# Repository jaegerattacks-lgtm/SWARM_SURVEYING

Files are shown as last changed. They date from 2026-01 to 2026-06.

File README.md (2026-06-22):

# SWARM SURVEYING

A modular robotics project for swarm-based surveying, combining robot bring-up, pose handling, mobile app integration, mechanical design, and supporting documentation in one repository.

## Overview

**SWARM SURVEYING** is a project archive for a surveying robot swarm workflow.  
This repository collects the main software packages, mobile app assets, hardware-related files, drawings, and technical appendices used across the project.

The goal of the project is to support a swarm surveying pipeline where robot motion, pose data, and system integration are handled through a coordinated software-and-hardware setup.

## What’s in this repository

- **Appendices** – technical background, design notes, and supporting documentation
- **Robot demo assets** – media showing robot movement and system behavior
- **ARKitRobotApp** – mobile app package for AR/pose-based interaction
- **PoseReceiver** – pose receiving component for system communication
- **Swarm bring-up** – bring-up package for launching or integrating the swarm system
- **Actuator sizing** – sizing and selection material for actuation
- **Parts** – parts list and component references
- **All drawings** – consolidated mechanical or system drawings

## Repository structure

```text
SWARM_SURVEYING/
├── appendices/
├── robot_moving_vid/
├── ARKitRobotApp.zip
├── PoseReceiver.zip
├── actutor_sizing.zip
├── all_drawings.zip
├── parts.zip
└── swarm_bringup-*.zip

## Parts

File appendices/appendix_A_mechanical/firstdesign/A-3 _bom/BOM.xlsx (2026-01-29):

 | Name | QTY | Material | model
1 | Plate | 1 | Acrylic | _
2 | Trailing Arm | 4 | Acrylic | _
3 | support_Arm | 4 | Acrylic | _
4 | spacer_link | 4 | Acrylic | _
5 | Trailing Arm_lcoker | 8 | Acrylic | _
6 | support_Arm_locker | 8 | Acrylic | _
7 | spacer_link_locker | 8 | Acrylic | _
8 | Rear Shaft Axle | 1 | Steel | _
9 | All terrain wheel | 4 | Rubber | _
10 | hex coupling long | 4 | brass | _
11 | Front shaft Axle | 1 | Steel | _
12 | camera holder | 2 | PLA | _
13 | Bearing | 16 | _ | F608ZZ
14 | shaft holder 8mm | 4 | steel | _
15 | suspension | 4 | _ | _
16 | Motor | 4 | _ | SG555123000-30K
17 | Motor Driver | 4 |  | BTS7960
18 | Battery | 9 | _ | _
19 | Esp 32 | 1 | _ | cp2102_30pin
20 | Pcb | 1 | _ | _
21 | BMS | 1 | _ | BMS 4S 18650
22 | Regulator | 1 | _ | _
23 | M3 Bolts 1.5cm | 36 | Steel | _
24 | M3 Bolts 2.5cm | 20 | steel | _
25 | M4 Bolts | 12 | Steel | _
26 | M3 Nuts | 64 | Steel | _
27 | M8 Nuts | 4 | Steel | _
28 | spacer 2cm | 16 | Steel | _
29 | Jumper Wires | 80 | Copper | _
30 | Macrona 1 meter | 7 | Plastic | _
31 | Mobile Iphone 12 | 1 | _ | _

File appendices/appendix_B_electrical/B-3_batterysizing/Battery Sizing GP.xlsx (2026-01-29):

Component | Quantity | Voltage | Current |  |  | Avg Power per unit | Avg Total Power | Max Power per unit | Max Total Power
 |  |  | Idle State | Nominal State | Peak State
Raspberry Pi 5 Model B 16 GB RAM | 1 | 5 | 1 | 2 | 3 | 10 | 10 | 15 | 15
ESP32-S Development Board CH340 | 1 | 3.3 | 0.02 | 0.15 | 0.6 | 0.495 | 0.495 | 1.98 | 1.98
MPU9250 | 1 | 3.3 | 8e-06 | 0.0037 | 0.004 | 0.01221 | 0.01221 | 0.0132 | 0.0132
VL53L1X | 2 | 3.3 | 2e-05 | 0.016 | 0.018 | 0.0528 | 0.1056 | 0.0594 | 0.1188
SG555123000-30K | 4 | 12 | 0.14 | 0.8 | 3 | 9.6 | 38.4 | 36 | 144
BTS7960 | 4 | 5 | - | 0.002 | 0.003 | 0.01 | 0.04 | 0.015 | 0.06
Calculations | Battery Model | INR18650MH1 |  | No. of cells in serires | 3 | - | Max Power | 161.172 | W
 | Desired Work Time | 2 | h | Pack Voltage | 11.1 | V | Avg Power | 49.05281 | W
 | Desired Voltage | 12 | V | No. of cells in parallel | 3 | - | Peak Current | 14.52 | A
 | Cell Voltage | 3.7 | V | Pack Capacity | 9.3 | Ah | Energy | 98.10562 | Wh
 | Cell Capacity | 3.1 | Ah | Pack max Current | 30 | A | Capacity | 8.838344144 | Ah
 | Cell max Current | 10 | A | Total No. of Cells | 9 | - | Min C-Rating | 1.642841664 | C
 |  |  |  | C_Rating | 3.225806452 | C

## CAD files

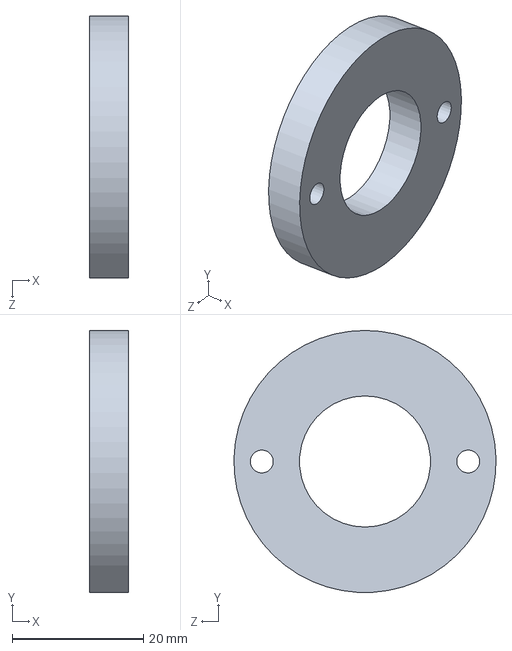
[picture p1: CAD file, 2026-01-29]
appendices/appendix_A_mechanical/firstdesign/A-1_3dcadmodels/Trailing_Arm bearing_locker.SLDPRT
6.00 x 40.0 x 40.0 mm

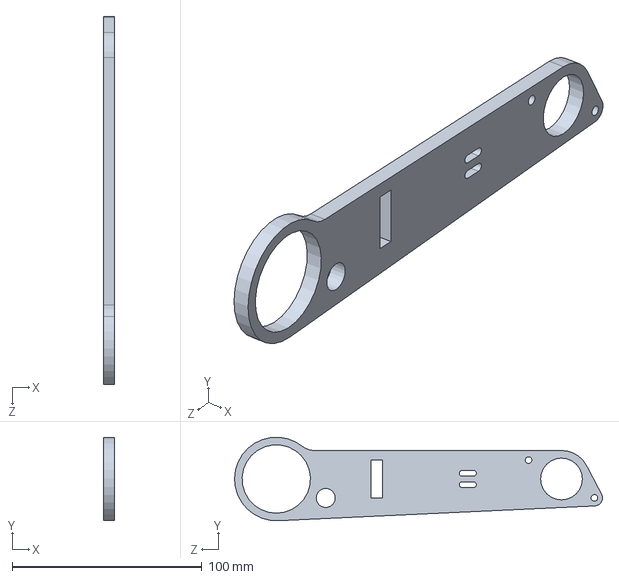
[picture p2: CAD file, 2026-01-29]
appendices/appendix_A_mechanical/firstdesign/A-1_3dcadmodels/Support Link.SLDPRT
6.00 x 43.9 x 193.8 mm

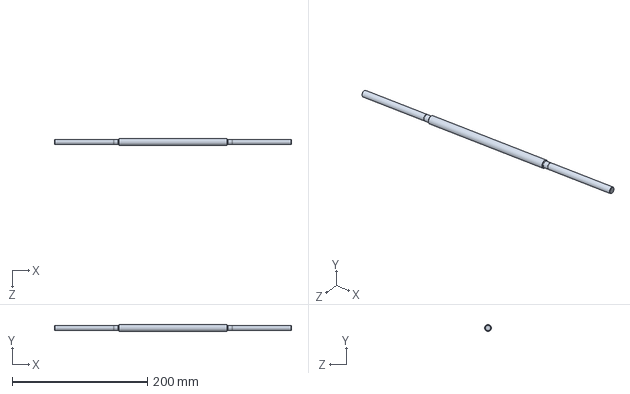
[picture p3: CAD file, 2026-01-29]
appendices/appendix_A_mechanical/firstdesign/A-1_3dcadmodels/Shaft.SLDPRT
350.0 x 10.0 x 10.0 mm

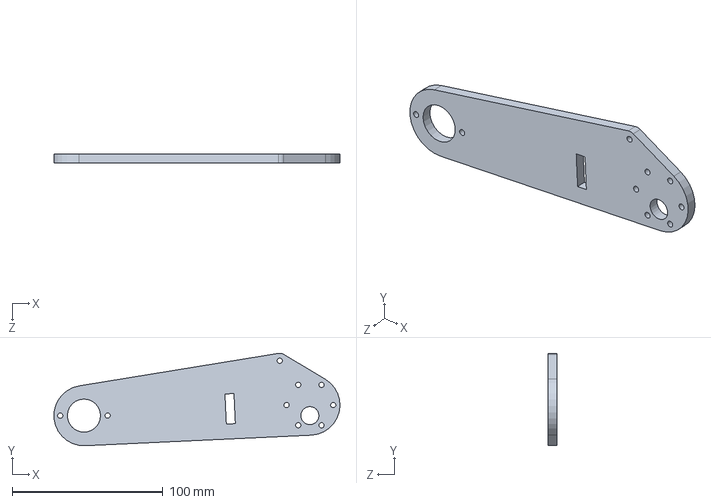
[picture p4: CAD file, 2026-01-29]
appendices/appendix_A_mechanical/firstdesign/A-1_3dcadmodels/Trailing Arm.SLDPRT
189.9 x 61.4 x 6.00 mm

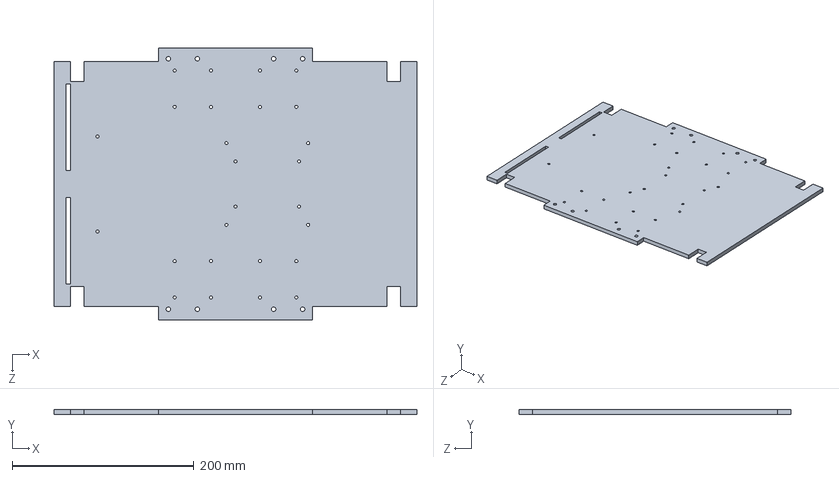
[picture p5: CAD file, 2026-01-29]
appendices/appendix_A_mechanical/firstdesign/A-1_3dcadmodels/Acrylic plate ___.SLDPRT
400.0 x 6.00 x 300.0 mm

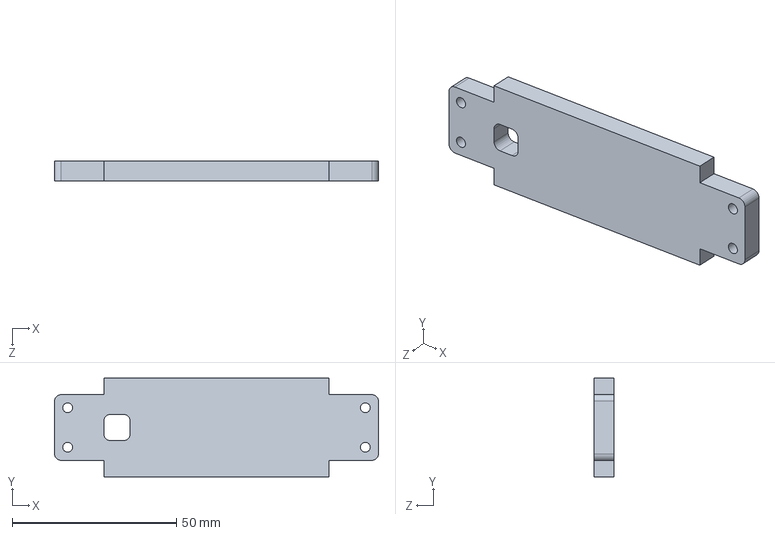
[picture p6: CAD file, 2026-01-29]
appendices/appendix_A_mechanical/firstdesign/A-1_3dcadmodels/Arms link.SLDPRT
98.5 x 30.0 x 6.00 mm

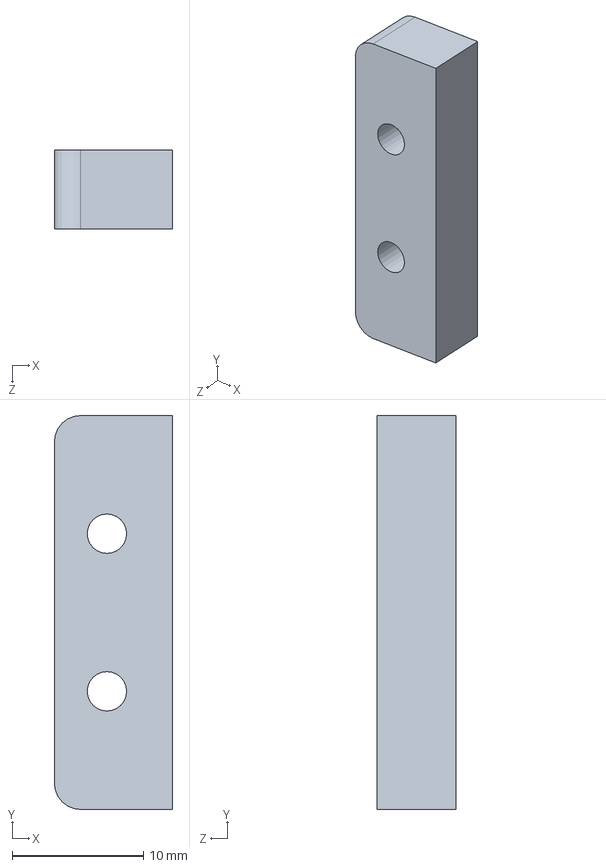
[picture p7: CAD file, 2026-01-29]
appendices/appendix_A_mechanical/firstdesign/A-1_3dcadmodels/spacer_link_locker.SLDPRT
9.00 x 30.0 x 6.00 mm

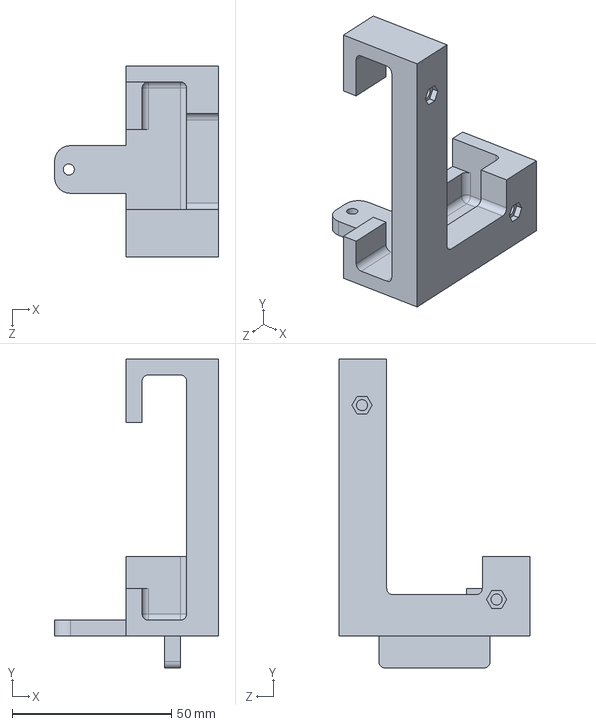
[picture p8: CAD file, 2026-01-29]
appendices/appendix_A_mechanical/firstdesign/A-1_3dcadmodels/fixed part.SLDPRT
51.5 x 97.0 x 60.0 mm

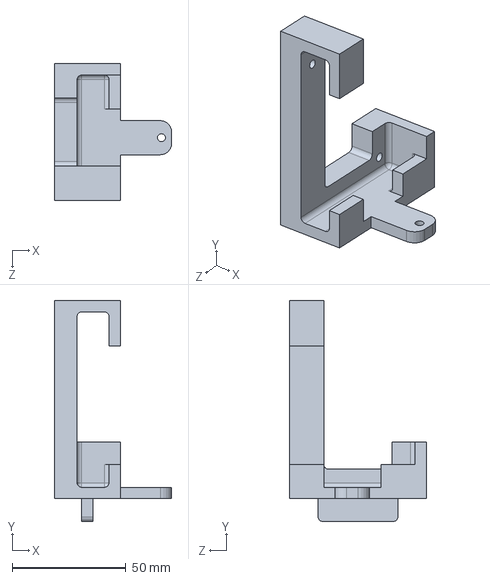
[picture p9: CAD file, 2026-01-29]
appendices/appendix_A_mechanical/firstdesign/A-1_3dcadmodels/fixed_part_mirror.SLDPRT
51.5 x 97.0 x 60.0 mm

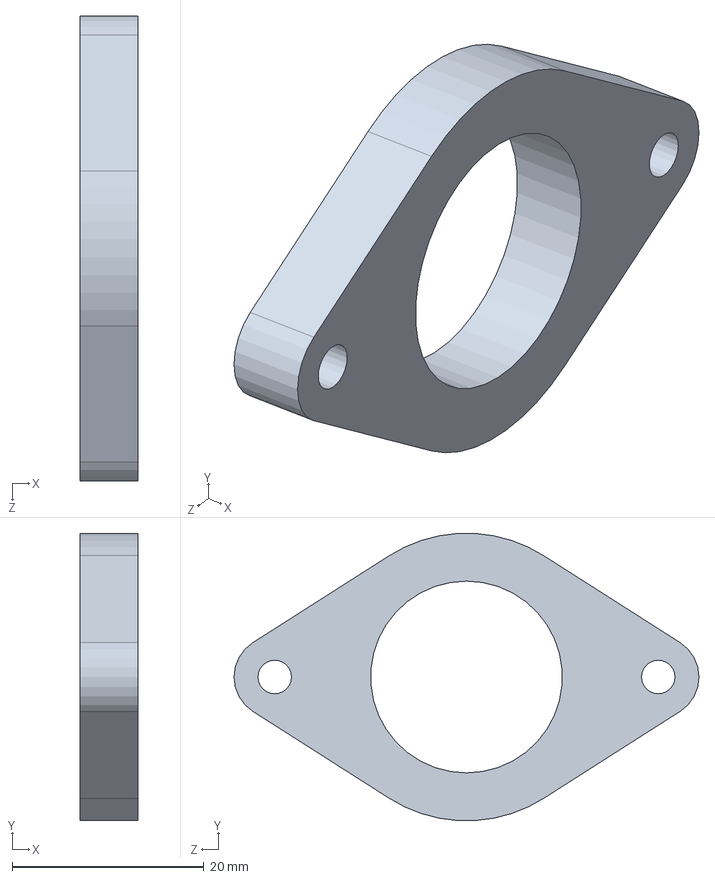
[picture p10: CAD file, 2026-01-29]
appendices/appendix_A_mechanical/firstdesign/A-1_3dcadmodels/support_link_locker.SLDPRT
6.00 x 29.9 x 48.5 mm

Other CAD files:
appendices/appendix_A_mechanical/firstdesign/A-1_3dcadmodels/spacer_link.SLDPRT

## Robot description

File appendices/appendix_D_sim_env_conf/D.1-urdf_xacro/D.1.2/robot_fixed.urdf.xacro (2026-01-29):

<?xml version="1.0"?>
<robot xmlns:xacro="http://www.ros.org/wiki/xacro" name="view_robot_pkg">

  <xacro:arg name="config_file" default=""/>

  <xacro:property name="mesh_path" value="file:///home/nour/my_friend_ws/install/swarm_bringup/share/swarm_bringup/meshes"/>
  
  <link name="base_link"></link>

  <link name="chassis_link">
    <inertial>
      <origin xyz="-0.001 0 0.009" rpy="0 0 0" />
      <mass value="3.0" />
      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
    </inertial>
    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
  </link>

  <joint name="base_to_chassis" type="fixed">
    <parent link="base_link" />
    <child link="chassis_link" />
    <origin xyz="0 0 0" rpy="0 0 0" />
  </joint>

  <xacro:macro name="leg_assembly" params="prefix arm_xyz damper_xyz wheel_xyz piston_xyz piston_rpy wheel_mu arm_inertial_xyz">

    <link name="${prefix}_arm">
      <inertial>
        <origin xyz="${arm_inertial_xyz}" rpy="0 0 0" />
        <mass value="0.147" />
        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
      </inertial>
      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
    </link>

    <joint name="${prefix}_arm_joint" type="revolute">
      <origin xyz="${arm_xyz}" rpy="1.5708 0 0" />
      <parent link="chassis_link" />
      <child link="${prefix}_arm" />
      <axis xyz="0 0 -1" />
      <limit lower="0" upper="0" effort="0" velocity="0" />
    </joint>

    <link name="${prefix}_piston">
      <inertial>
        <origin xyz="0 0 0" rpy="0 0 0" />
        <mass value="0.001" />
        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
      </inertial>
      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
      </link>

    <joint name="${prefix}_piston_joint" type="revolute">
      <origin xyz="${piston_xyz}" rpy="${piston_rpy}" />
      <parent link="${prefix}_arm" />
      <child link="${prefix}_piston" />
      <axis xyz="0 0 -1" />
      <limit lower="0" upper="0" effort="0" velocity="0" />
    </joint>

    <link name="${prefix}_damper">
      <inertial>
        <origin xyz="0 0 0" rpy="0 0 0" />
        <mass value="0.018" />
        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
      </inertial>
      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
      </link>

    <joint name="${prefix}_damper_joint" type="revolute">
      <origin xyz="${damper_xyz}" rpy="1.5708 0 0" />
      <parent link="chassis_link" />
      <child link="${prefix}_damper" />
      <axis xyz="0 0 -1" />
      <limit lower="0" upper="0" effort="0" velocity="0" />
    </joint>

    <link name="${prefix}_wheel">
      <inertial>
        <origin xyz="0 0 0" rpy="0 0 0" />
        <mass value="0.096" />
        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
      </inertial>
      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
    </link>

    <joint name="${prefix}_wheel_joint" type="continuous">
      <origin xyz="${wheel_xyz}" rpy="0 0 0" />
      <parent link="${prefix}_arm" />
      <child link="${prefix}_wheel" />
      <axis xyz="0 0 -1" />
    </joint>

    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

  </xacro:macro>

  <xacro:leg_assembly prefix="front_right" arm_xyz="0.059 -0.154 -0.026" damper_xyz="0.175 -0.147 0.081" wheel_xyz="0.136 -0.061 0.058" piston_xyz="0.133 0.020 -0.007" piston_rpy="0 0 0" wheel_mu="1.2" arm_inertial_xyz="0.117 -0.045 -0.033" />

  <xacro:leg_assembly prefix="front_left" arm_xyz="0.059 0.154 -0.026" damper_xyz="0.175 0.147 0.081" wheel_xyz="0.136 -0.061 -0.058" piston_xyz="0.133 -0.02 0.007" piston_rpy="0 0 0" wheel_mu="1.2" arm_inertial_xyz="0.119 -0.039 0.033" />

  <xacro:leg_assembly prefix="back_right" arm_xyz="-0.056 -0.154 -0.026" damper_xyz="-0.172 -0.147 0.081" wheel_xyz="-0.136 -0.061 0.058" piston_xyz="-0.133 -0.020 -0.007" piston_rpy="0 0 0" wheel_mu="0.01" arm_inertial_xyz="-0.117 -0.045 -0.033" />

  <xacro:leg_assembly prefix="back_left" arm_xyz="-0.056 0.154 -0.026" damper_xyz="-0.172 0.147 0.081" wheel_xyz="-0.136 -0.061 -0.058" piston_xyz="-0.133 -0.020 0.007" piston_rpy="0 0 0" wheel_mu="0.01" arm_inertial_xyz="-0.117 -0.044 0.033" />

  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

  <link name="camera_link">
    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
    <inertial>
      <mass value="0.05"/>
      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
    </inertial>
  </link>

  <joint name="camera_joint" type="fixed">
    <parent link="chassis_link"/>
    <child link="camera_link"/>
    <origin xyz="0.18 0.05 0.06" rpy="0 0 0"/>
  </joint>

  <link name="camera_link_optical"></link>
  <joint name="camera_optical_joint" type="fixed">
    <parent link="camera_link"/>
    <child link="camera_link_optical"/>
    <origin xyz="0 0 0" rpy="-1.5708 0 -1.5708"/>
  </joint>

  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

  <ros2_control name="GazeboSystem" type="system">
    <hardware>
      <plugin>gazebo_ros2_control/GazeboSystem</plugin>
    </hardware>

    <xacro:macro name="wheel_interface" params="prefix">
      <joint name="${prefix}_wheel_joint">
        <command_interface name="velocity">
          <param name="min">-10</param>
          <param name="max">10</param>
        </command_interface>
        <state_interface name="velocity"/>
        <state_interface name="position"/>
      </joint>
    </xacro:macro>
    <xacro:wheel_interface prefix="front_left"/>
    <xacro:wheel_interface prefix="front_right"/>
    <xacro:wheel_interface prefix="back_left"/>
    <xacro:wheel_interface prefix="back_right"/>

    <xacro:macro name="passive_interface" params="prefix suffix">
      <joint name="${prefix}_${suffix}_joint">
        <state_interface name="position"/>
      </joint>
    </xacro:macro>
    <xacro:passive_interface prefix="front_left" suffix="arm"/>
    <xacro:passive_interface prefix="front_right" suffix="arm"/>
    <xacro:passive_interface prefix="back_left" suffix="arm"/>
    <xacro:passive_interface prefix="back_right" suffix="arm"/>
    <xacro:passive_interface prefix="front_left" suffix="piston"/>
    <xacro:passive_interface prefix="front_right" suffix="piston"/>
    <xacro:passive_interface prefix="back_left" suffix="piston"/>
    <xacro:passive_interface prefix="back_right" suffix="piston"/>
    <xacro:passive_interface prefix="front_left" suffix="damper"/>
    <xacro:passive_interface prefix="front_right" suffix="damper"/>
    <xacro:passive_interface prefix="back_left" suffix="damper"/>
    <xacro:passive_interface prefix="back_right" suffix="damper"/>
  </ros2_control>

  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

</robot>

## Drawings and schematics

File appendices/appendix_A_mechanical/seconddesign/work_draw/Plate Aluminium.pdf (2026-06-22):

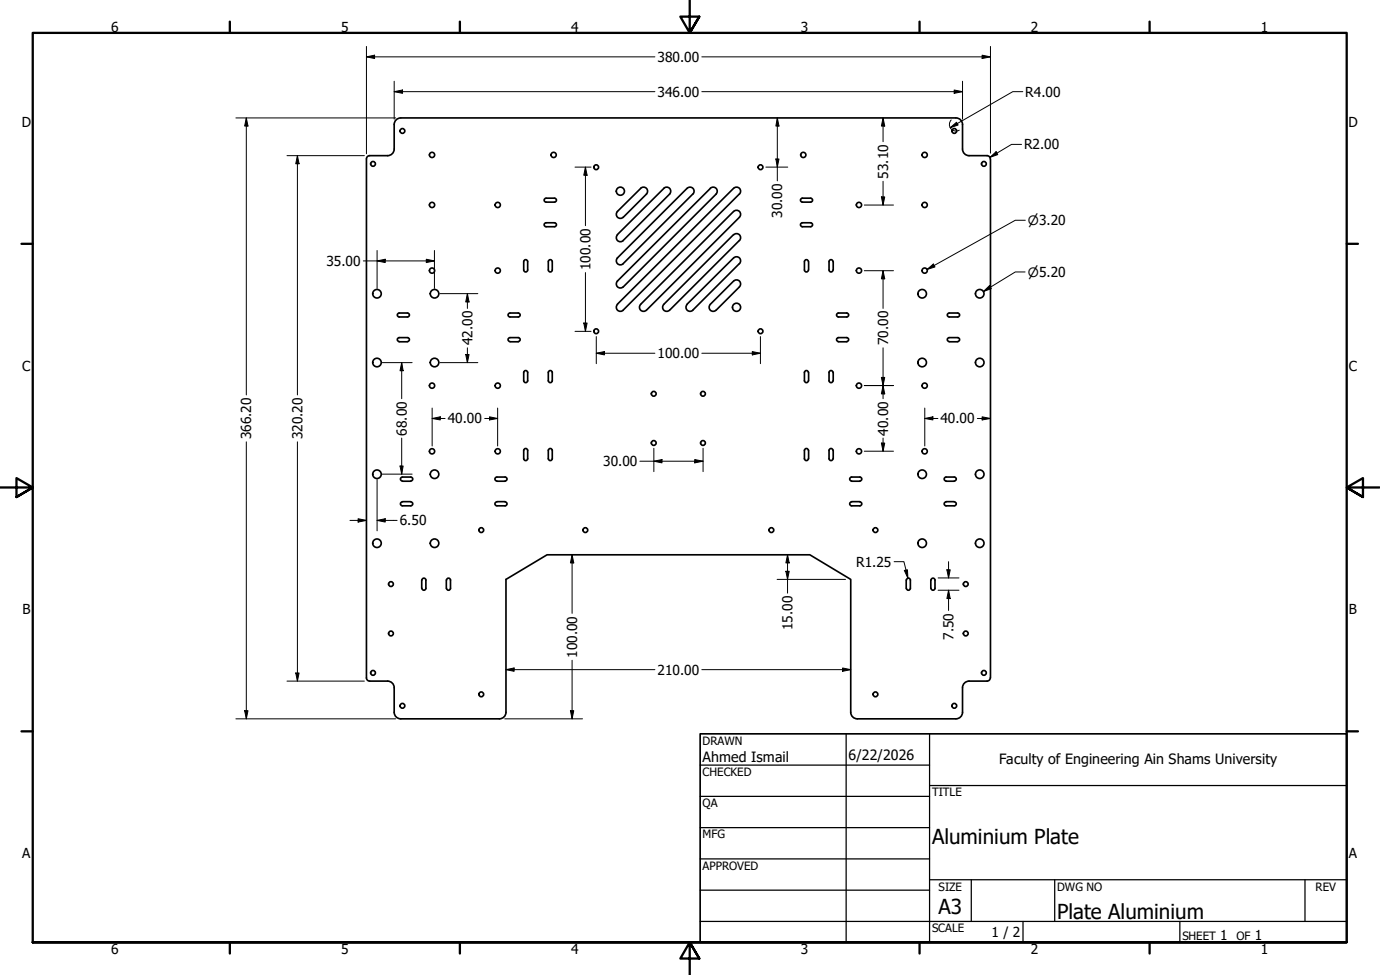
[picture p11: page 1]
Aluminium Plate

DRAWN Ahmed Ismail | 6/22/2026 | Faculty of Engineering Ain Shams University

CHECKED

MFG

APPROVED

SIZE A3 | DWG NO Plate Aluminium | REV

SCALE 1 / 2 | | SHEET 1 OF 1

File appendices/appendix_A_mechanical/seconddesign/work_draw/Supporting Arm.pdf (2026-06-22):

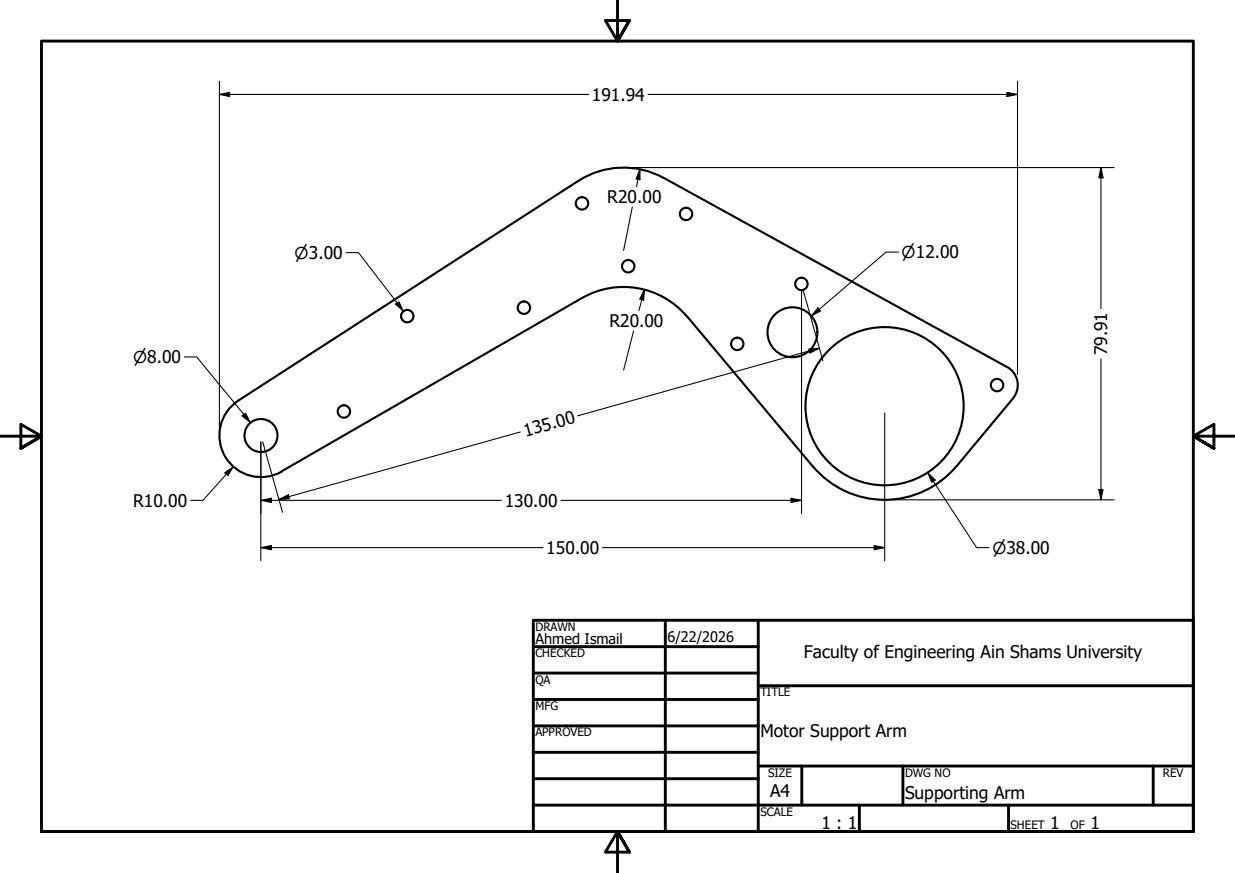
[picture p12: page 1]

DRAWN Ahmed Ismail | 6/22/2026 | Faculty of Engineering Ain Shams University

CHECKED

MFG

APPROVED

Motor Support Arm

SIZE A4 | DWG NO Supporting Arm | REV

SCALE 1 : 1 | | SHEET 1 OF 1

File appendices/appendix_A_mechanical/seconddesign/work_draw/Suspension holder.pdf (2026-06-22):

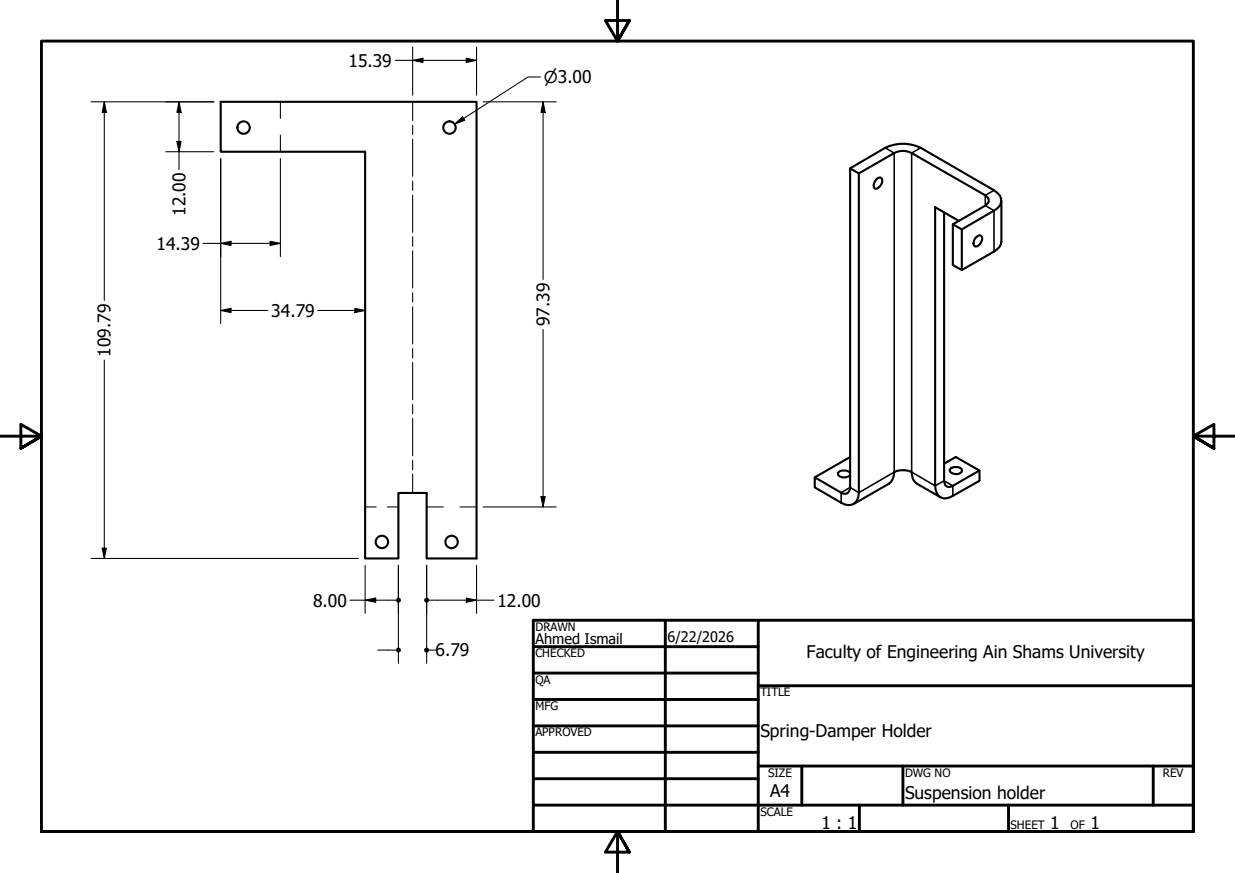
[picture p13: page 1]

DRAWN Ahmed Ismail | 6/22/2026 | Faculty of Engineering Ain Shams University

CHECKED

MFG

APPROVED

Spring-Damper Holder

SIZE A4 | DWG NO Suspension holder | REV

SCALE 1 : 1 | | SHEET 1 OF 1

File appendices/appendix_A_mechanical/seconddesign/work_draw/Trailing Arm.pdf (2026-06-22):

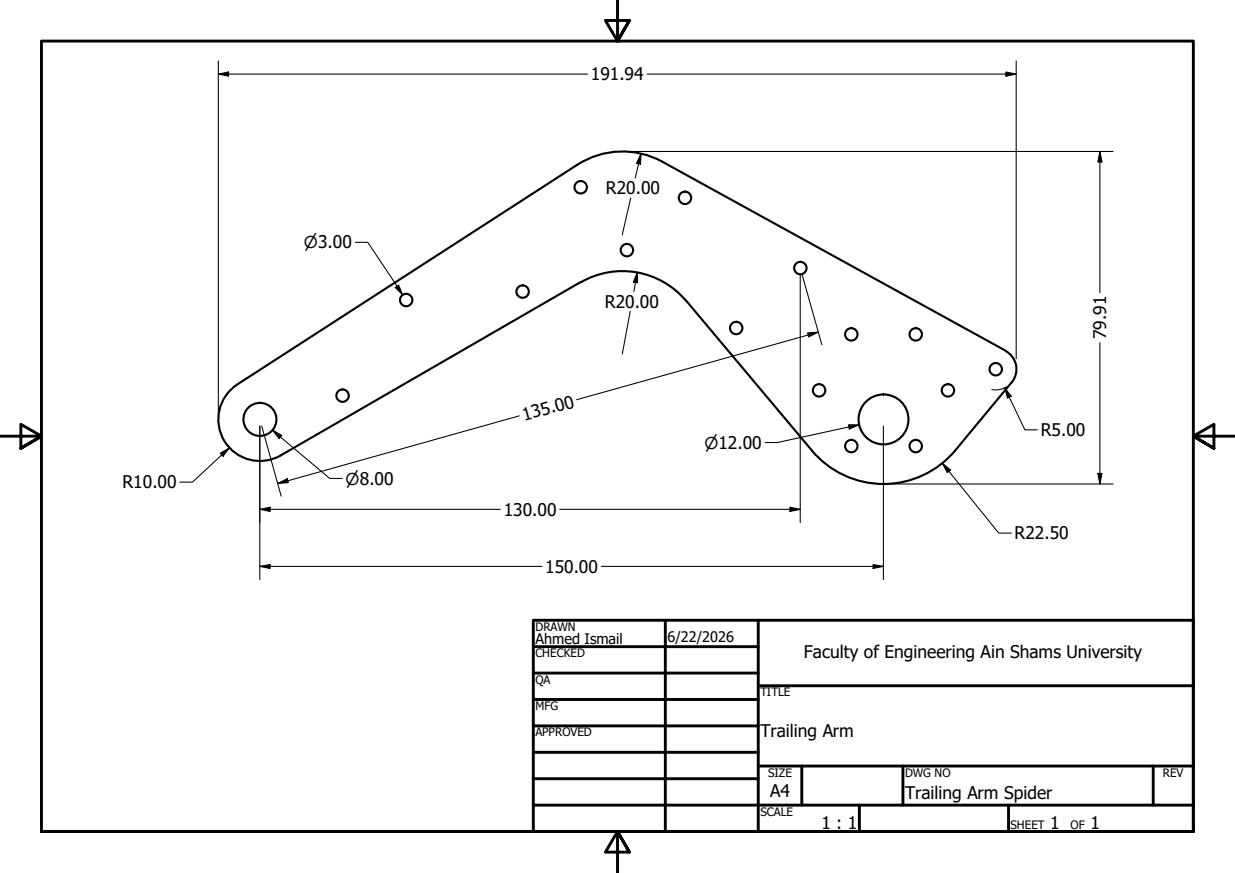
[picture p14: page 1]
Trailing Arm

DRAWN Ahmed Ismail | 6/22/2026 | Faculty of Engineering Ain Shams University

CHECKED

MFG

APPROVED

SIZE A4 | DWG NO Trailing Arm Spider | REV

SCALE 1 : 1 | | SHEET 1 OF 1

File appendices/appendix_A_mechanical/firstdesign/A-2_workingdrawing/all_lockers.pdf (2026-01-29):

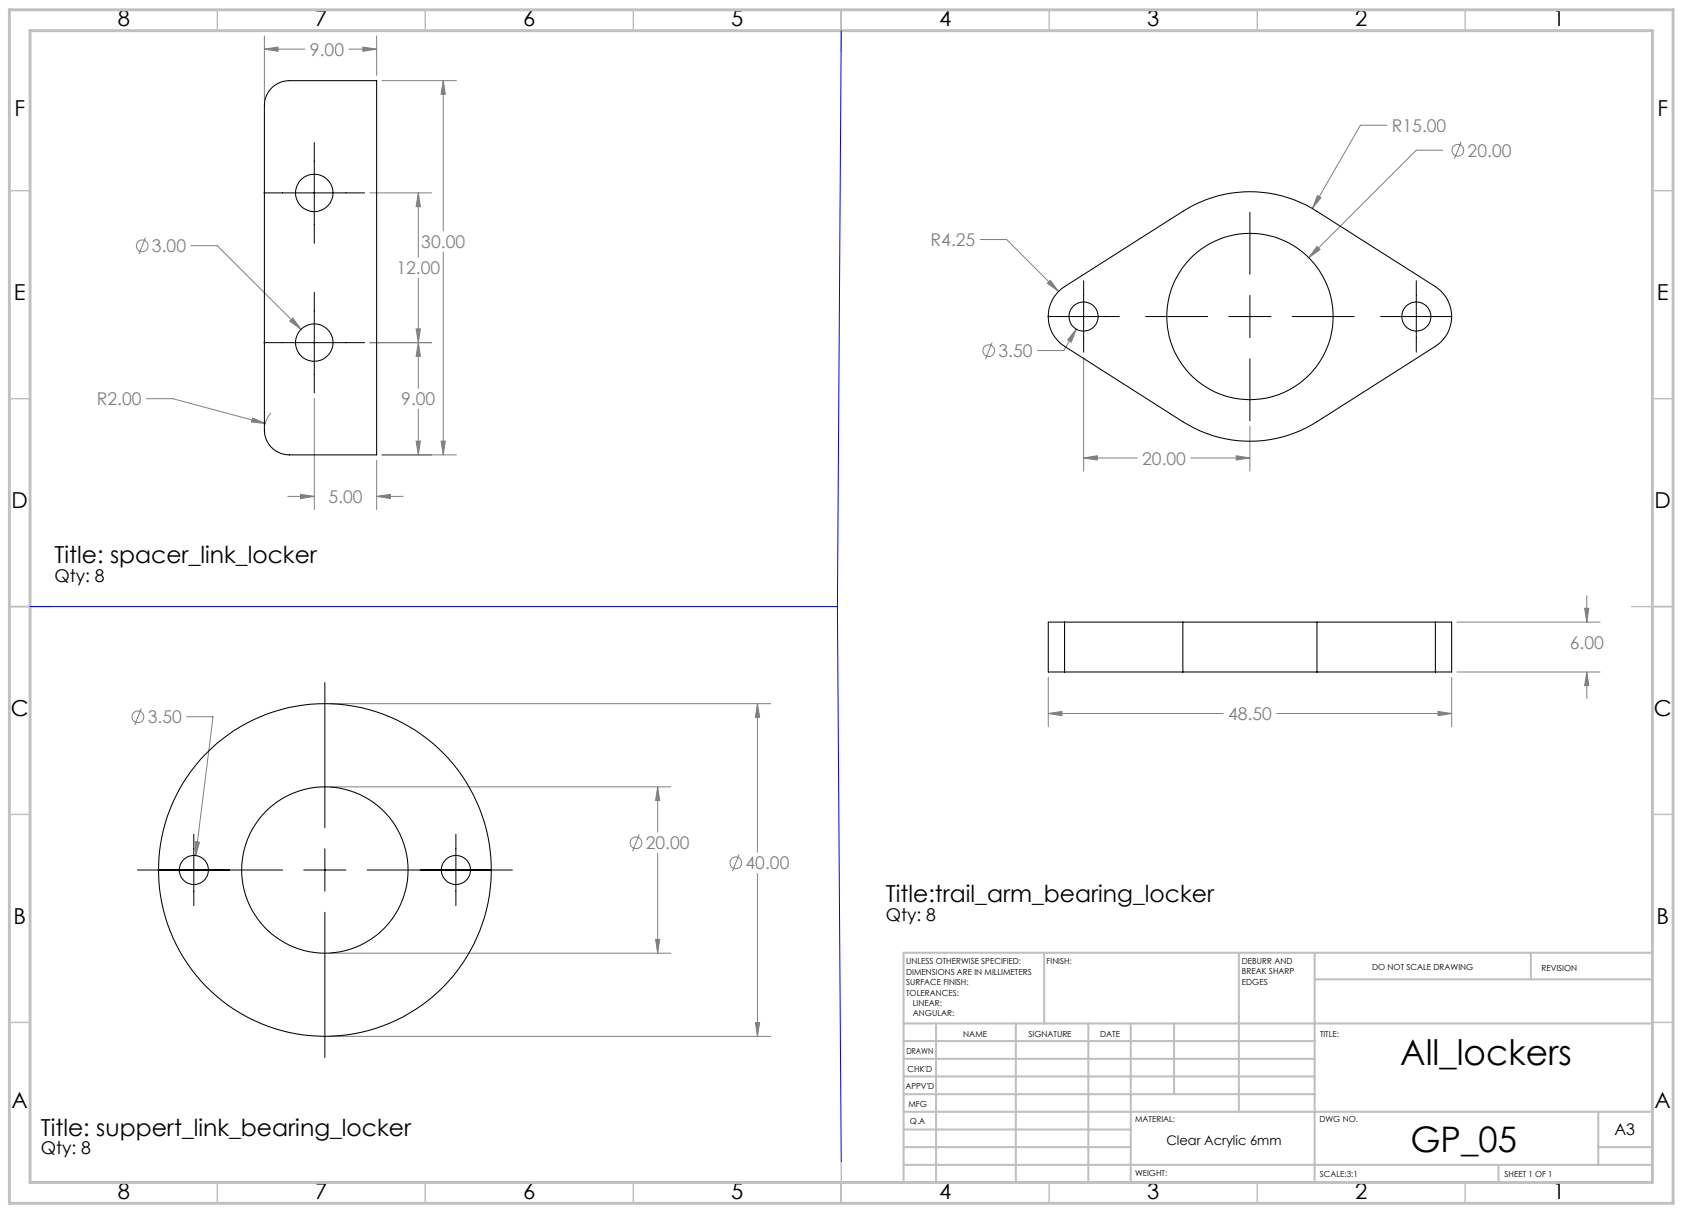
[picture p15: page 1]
Title: spacer_link_locker Qty: 8; Qty: 8; Title: suppert_link_bearing_locker Qty: 8; FINISH:; DEBURR AND; BREAK SHARP; DO NOT SCALE DRAWING; REVISION; SCALE:3:1; SHEET 1 OF 1

UNLESS OTHERWISE SPECIFIED:
DIMENSIONS ARE IN MILLIMETERS
SURFACE FINISH:
TOLERANCES:
LINEAR:
ANGULAR:

NAME | SIGNATURE | DATE | | | | TITLE: All_lockers

DRAWN
CHK'D
APPV'D
MFG
Q.A | | | | MATERIAL: | DWG NO. GP_05 | A3 Clear Acrylic 6mm

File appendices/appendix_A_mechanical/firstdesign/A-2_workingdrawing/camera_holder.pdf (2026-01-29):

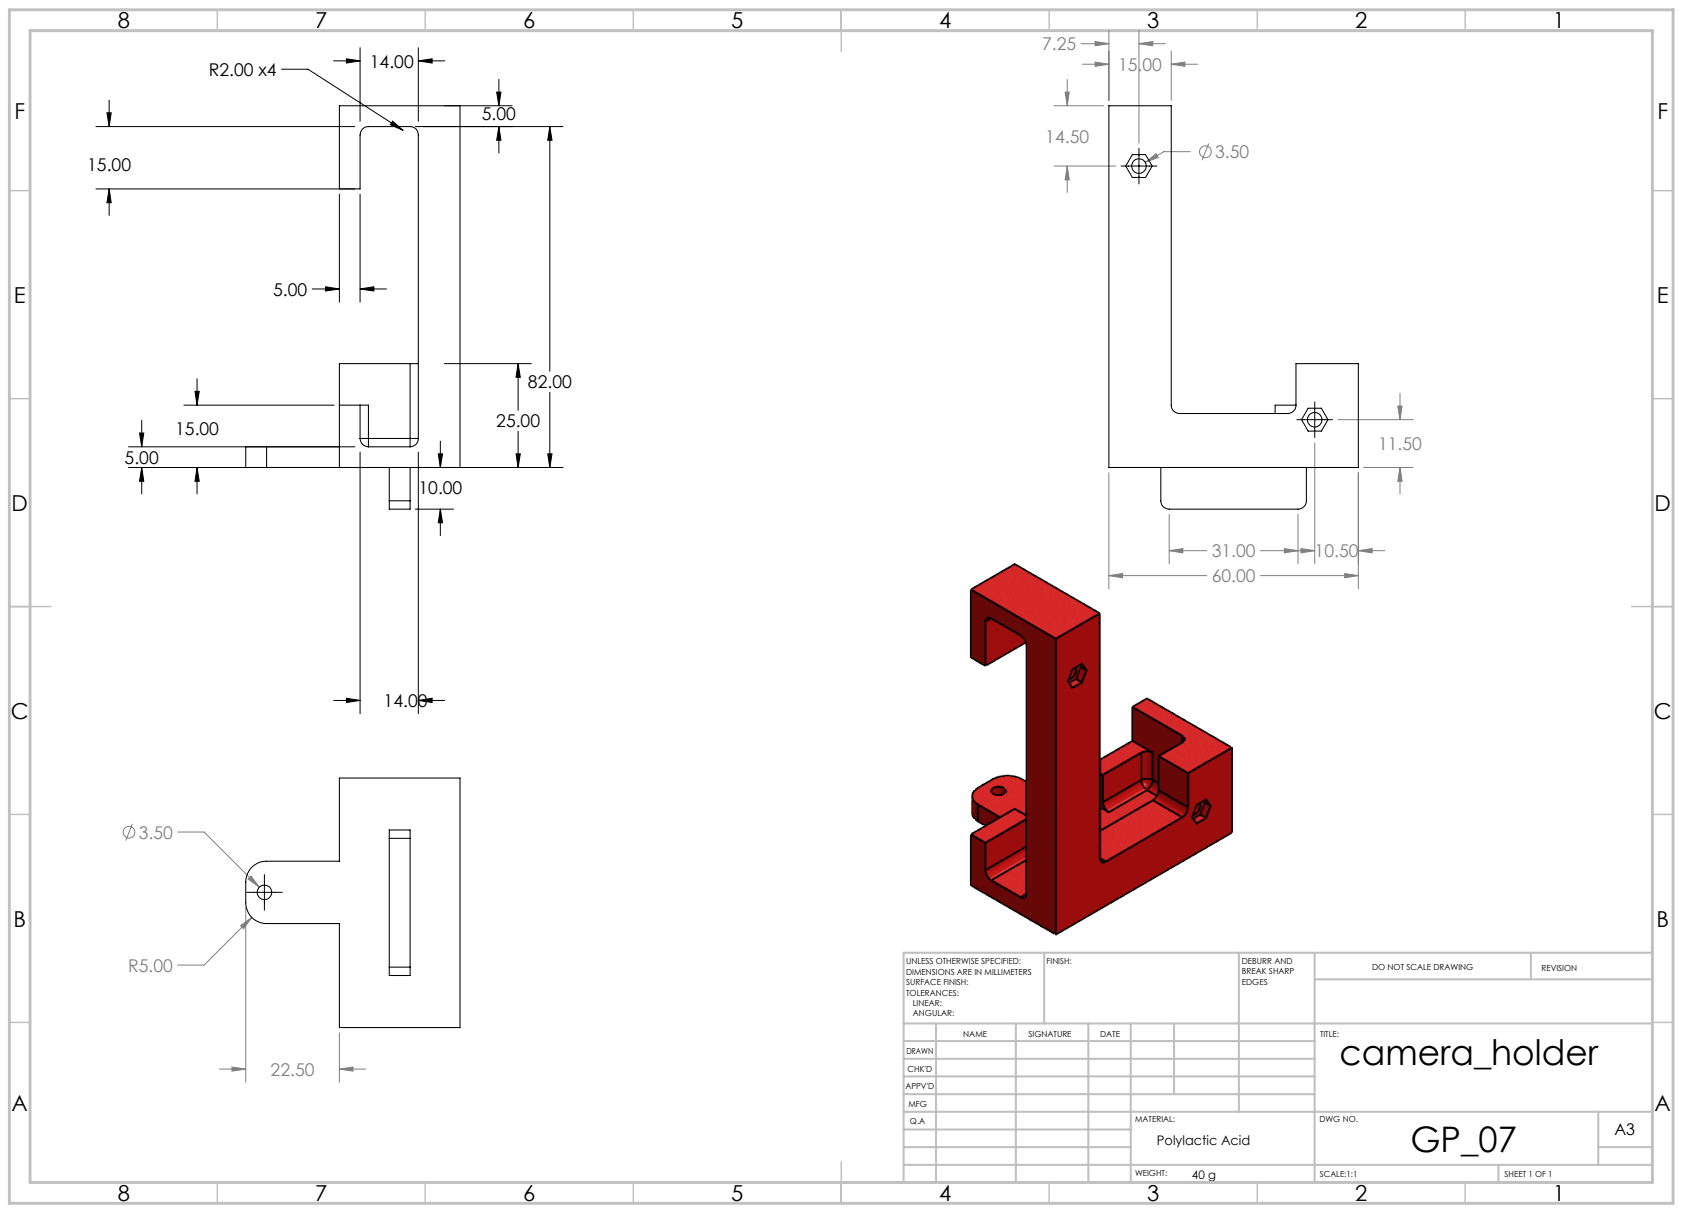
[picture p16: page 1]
FINISH:; DEBURR AND; BREAK SHARP; DO NOT SCALE DRAWING; REVISION; SCALE:1:1; SHEET 1 OF 1

UNLESS OTHERWISE SPECIFIED:
DIMENSIONS ARE IN MILLIMETERS
SURFACE FINISH:
TOLERANCES:
LINEAR:
ANGULAR:

NAME | SIGNATURE | DATE | | | | TITLE: camera_holder

DRAWN
CHK'D
APPV'D
MFG
Q.A | | | | MATERIAL: | DWG NO. GP_07 | A3 Polylactic Acid

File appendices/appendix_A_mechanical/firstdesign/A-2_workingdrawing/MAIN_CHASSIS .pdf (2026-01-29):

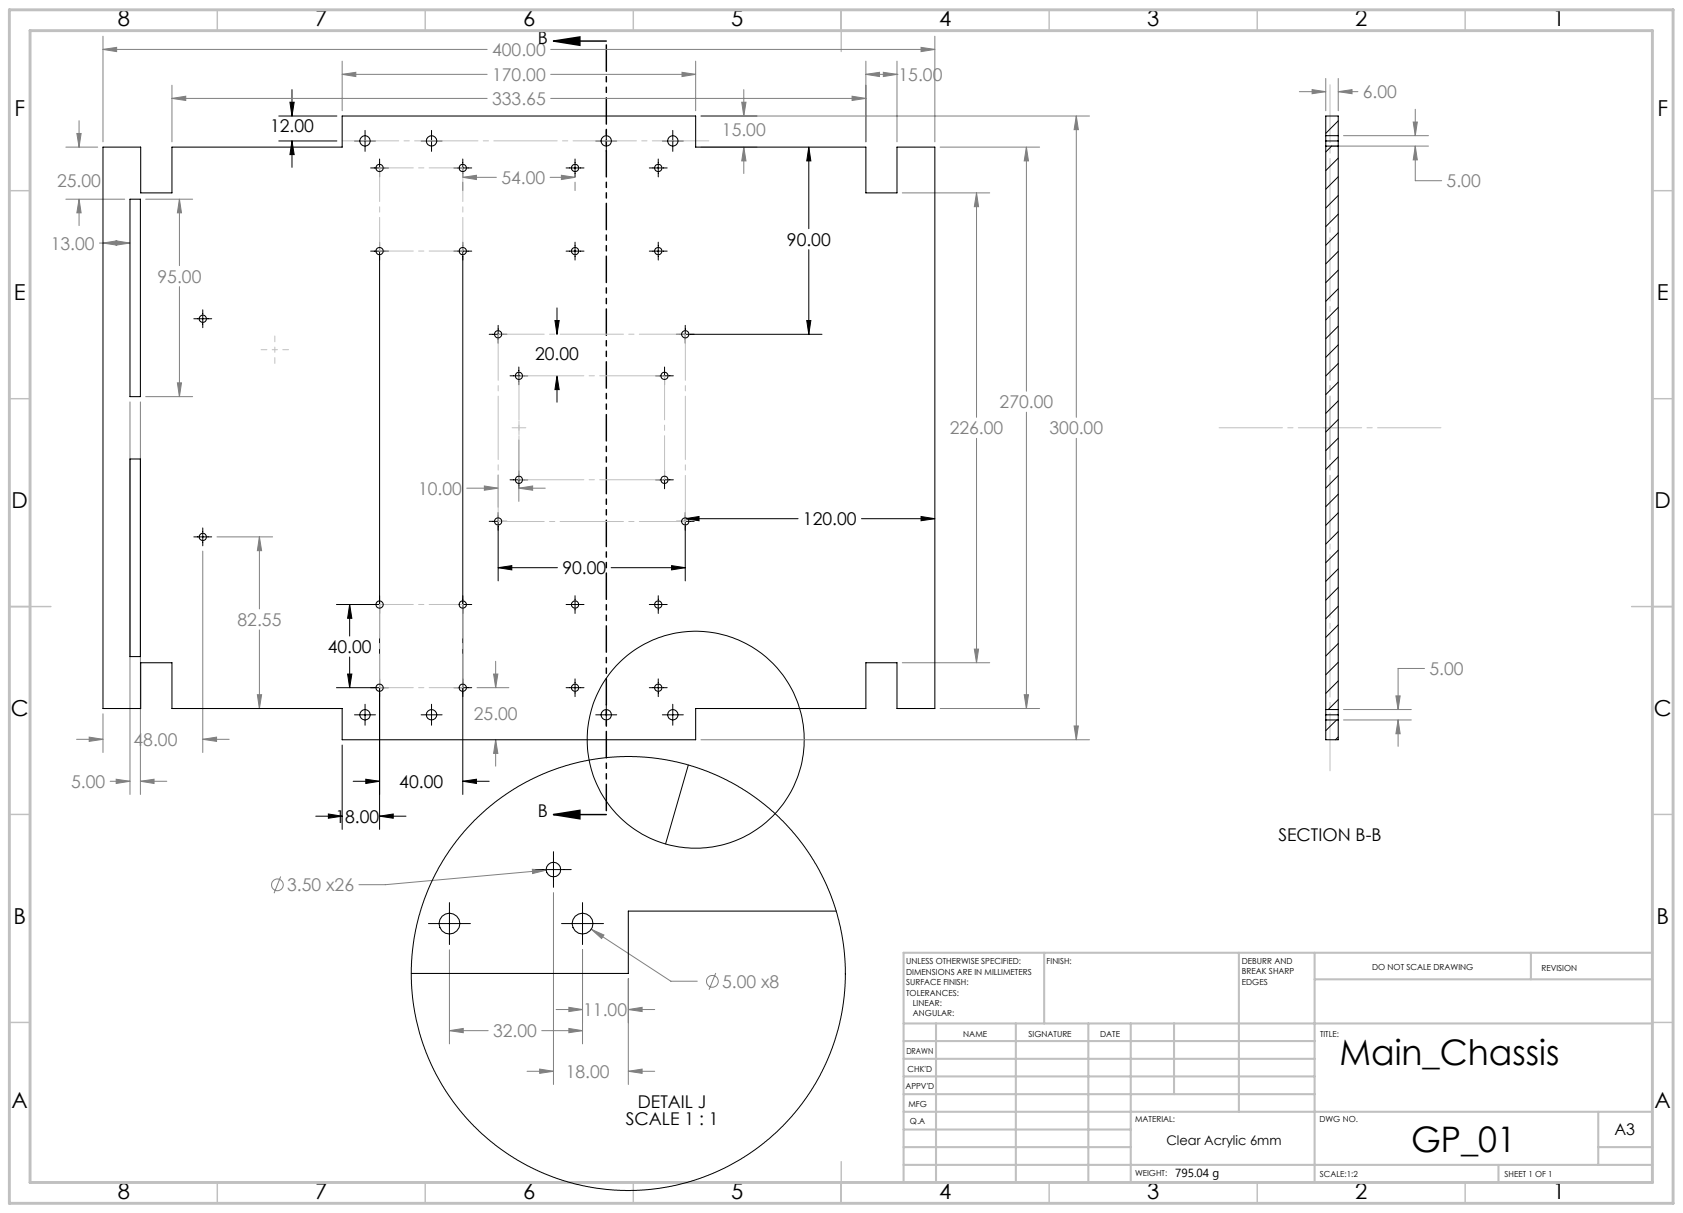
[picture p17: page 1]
SECTION B-B; DETAIL J SCALE 1 : 1; FINISH:; DEBURR AND; BREAK SHARP; DO NOT SCALE DRAWING; REVISION; SCALE:1:2; SHEET 1 OF 1

UNLESS OTHERWISE SPECIFIED:
DIMENSIONS ARE IN MILLIMETERS
SURFACE FINISH:
TOLERANCES:
LINEAR:
ANGULAR:

NAME | SIGNATURE | DATE | | | | TITLE: Main_Chassis

DRAWN
CHK'D
APPV'D
MFG
Q.A | | | | MATERIAL: | DWG NO. GP_01 | A3 Clear Acrylic 6mm

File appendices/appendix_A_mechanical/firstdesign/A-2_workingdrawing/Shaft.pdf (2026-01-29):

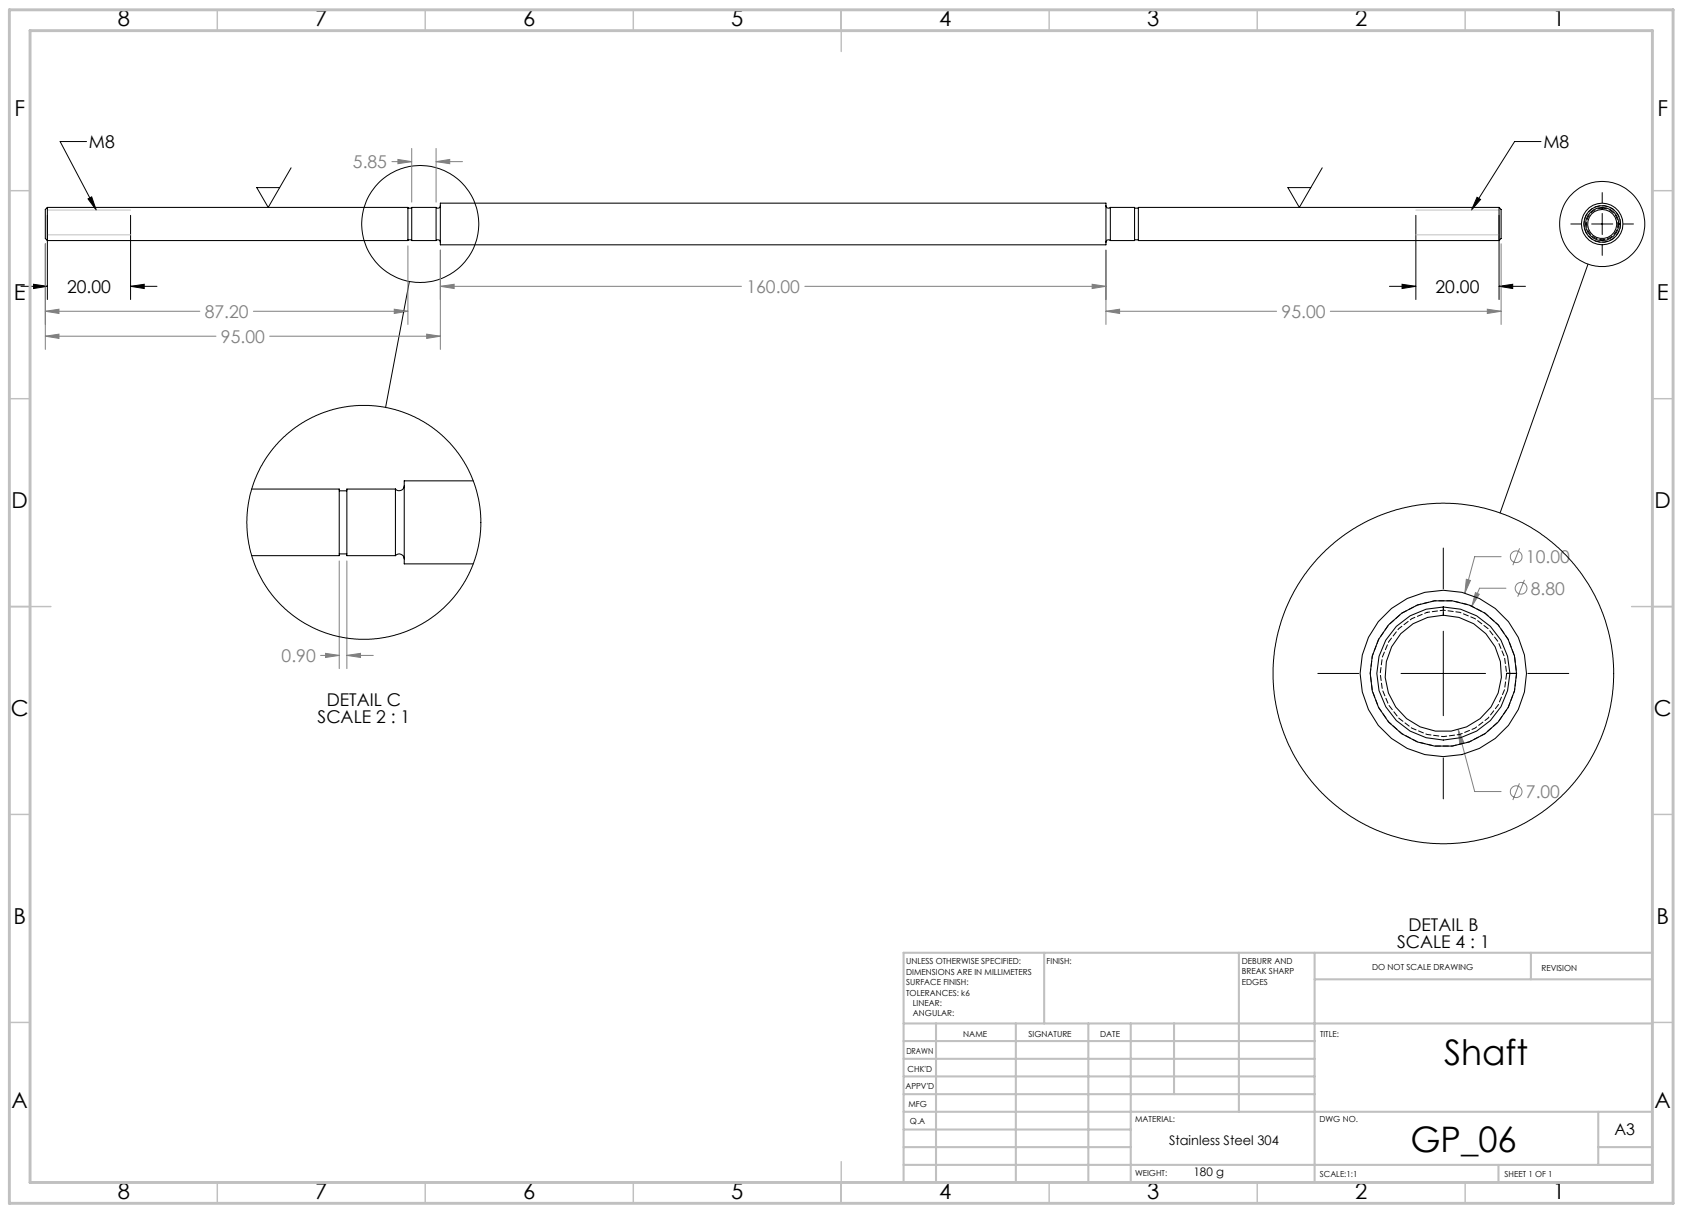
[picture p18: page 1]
DETAIL B SCALE 4 : 1; DETAIL C SCALE 2 : 1; FINISH:; DEBURR AND; BREAK SHARP; DO NOT SCALE DRAWING; REVISION; SCALE:1:1; SHEET 1 OF 1

UNLESS OTHERWISE SPECIFIED:
DIMENSIONS ARE IN MILLIMETERS
SURFACE FINISH:
TOLERANCES: k6
LINEAR:
ANGULAR:

NAME | SIGNATURE | DATE | | | | TITLE: Shaft

DRAWN
CHK'D
APPV'D
MFG
Q.A | | | | MATERIAL: | DWG NO. GP_06 | A3 Stainless Steel 304

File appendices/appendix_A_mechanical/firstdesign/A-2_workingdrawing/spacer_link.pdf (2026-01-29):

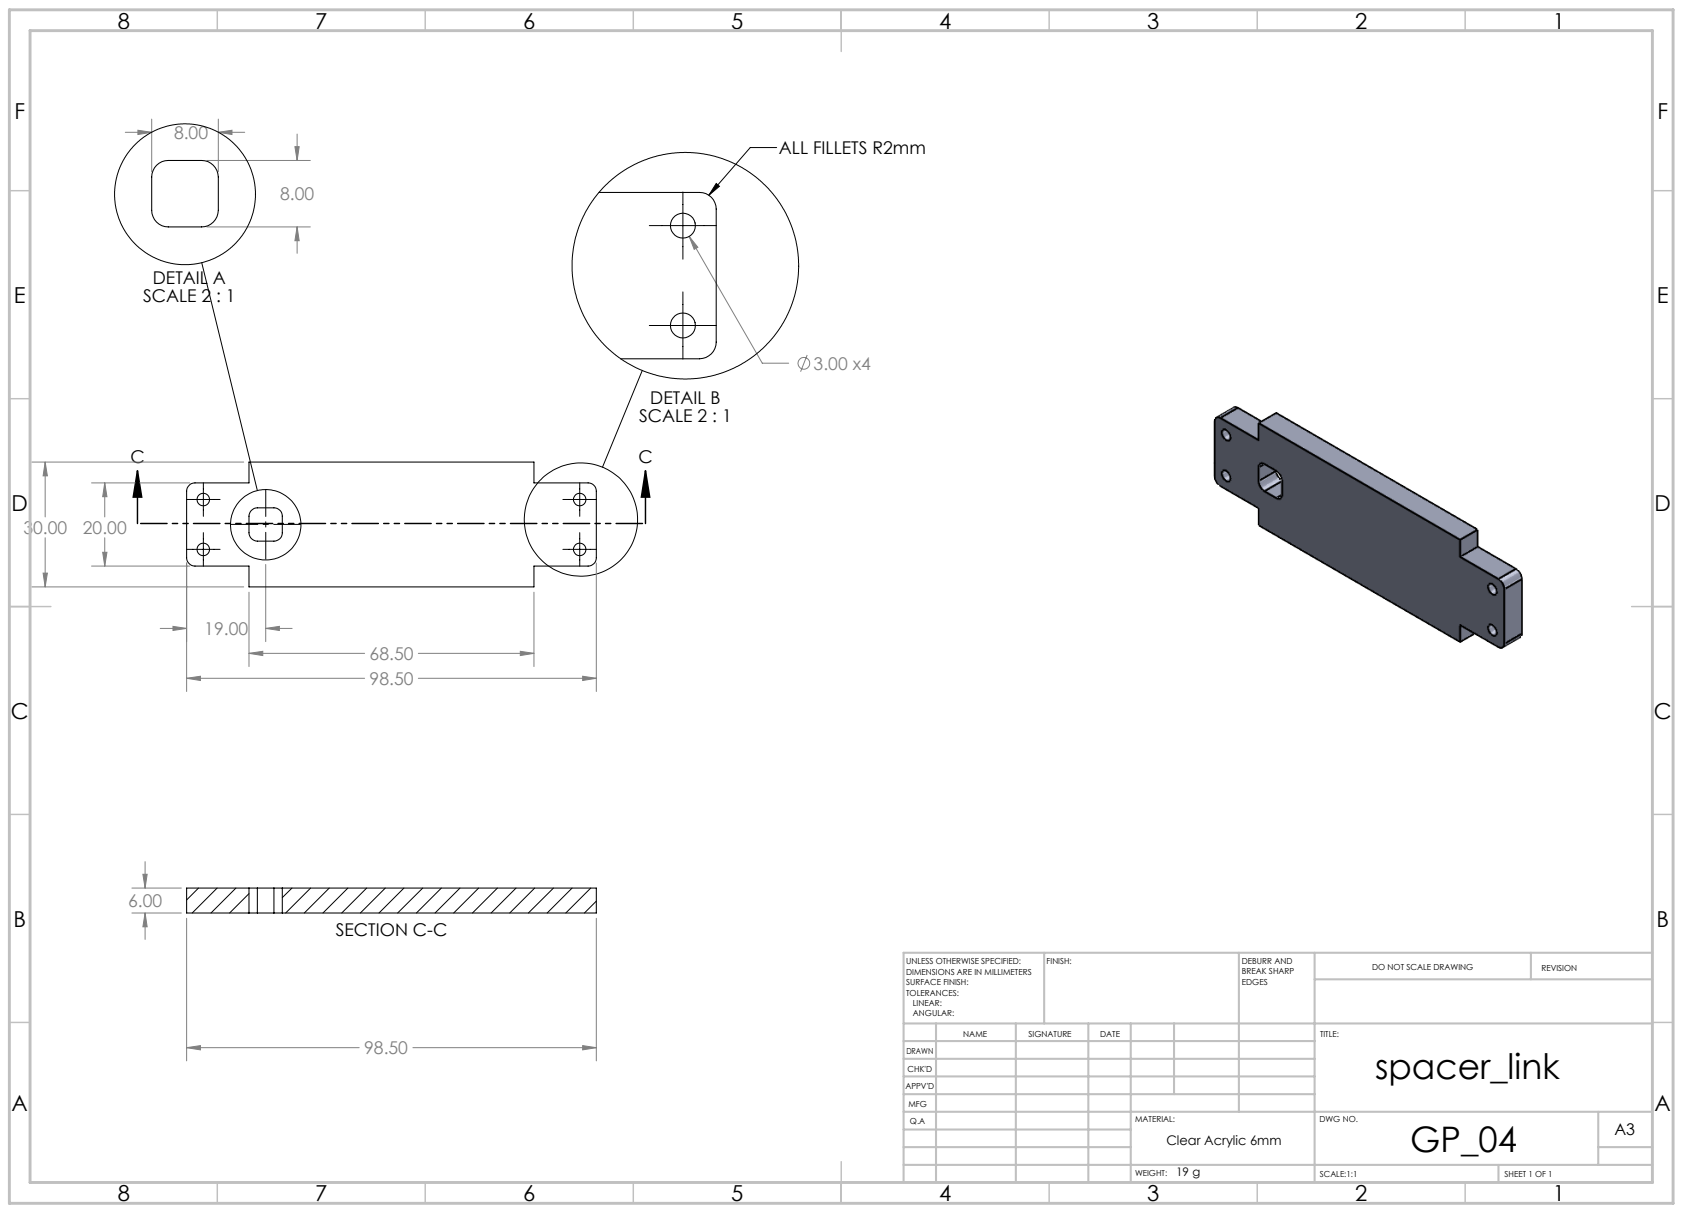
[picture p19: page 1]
DETAIL A SCALE 2 : 1; DETAIL B SCALE 2 : 1; ALL FILLETS R2mm; SECTION C-C; FINISH:; DEBURR AND; BREAK SHARP; DO NOT SCALE DRAWING; REVISION; SCALE:1:1; SHEET 1 OF 1

UNLESS OTHERWISE SPECIFIED:
DIMENSIONS ARE IN MILLIMETERS
SURFACE FINISH:
TOLERANCES:
LINEAR:
ANGULAR:

NAME | SIGNATURE | DATE | | | | TITLE: spacer_link

DRAWN
CHK'D
APPV'D
MFG
Q.A | | | | MATERIAL: | DWG NO. GP_04 | A3 Clear Acrylic 6mm

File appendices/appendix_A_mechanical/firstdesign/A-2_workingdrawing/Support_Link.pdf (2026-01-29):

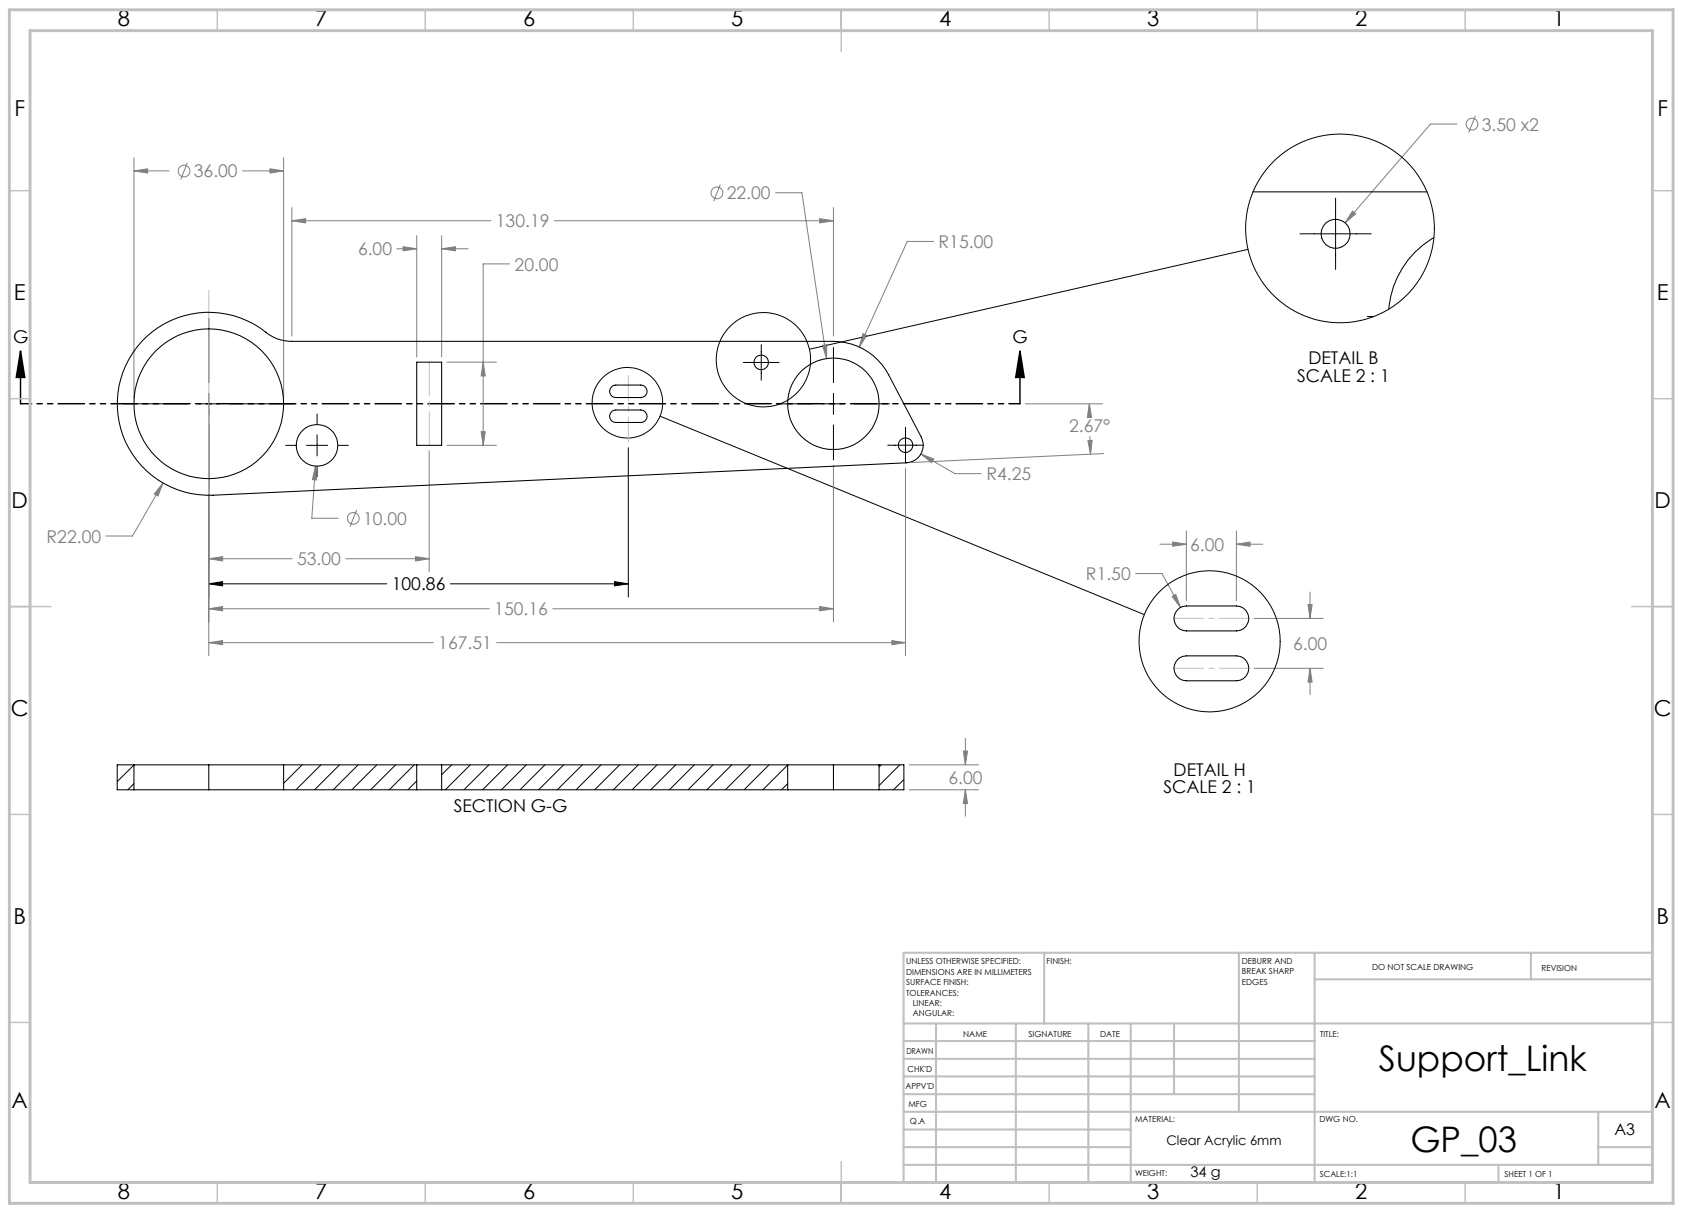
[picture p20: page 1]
DETAIL B SCALE 2 : 1; SECTION G-G; DETAIL H SCALE 2 : 1; FINISH:; DEBURR AND; BREAK SHARP; DO NOT SCALE DRAWING; REVISION; SCALE:1:1; SHEET 1 OF 1

UNLESS OTHERWISE SPECIFIED:
DIMENSIONS ARE IN MILLIMETERS
SURFACE FINISH:
TOLERANCES:
LINEAR:
ANGULAR:

NAME | SIGNATURE | DATE | | | | TITLE: Support_Link

DRAWN
CHK'D
APPV'D
MFG
Q.A | | | | MATERIAL: | DWG NO. GP_03 | A3 Clear Acrylic 6mm

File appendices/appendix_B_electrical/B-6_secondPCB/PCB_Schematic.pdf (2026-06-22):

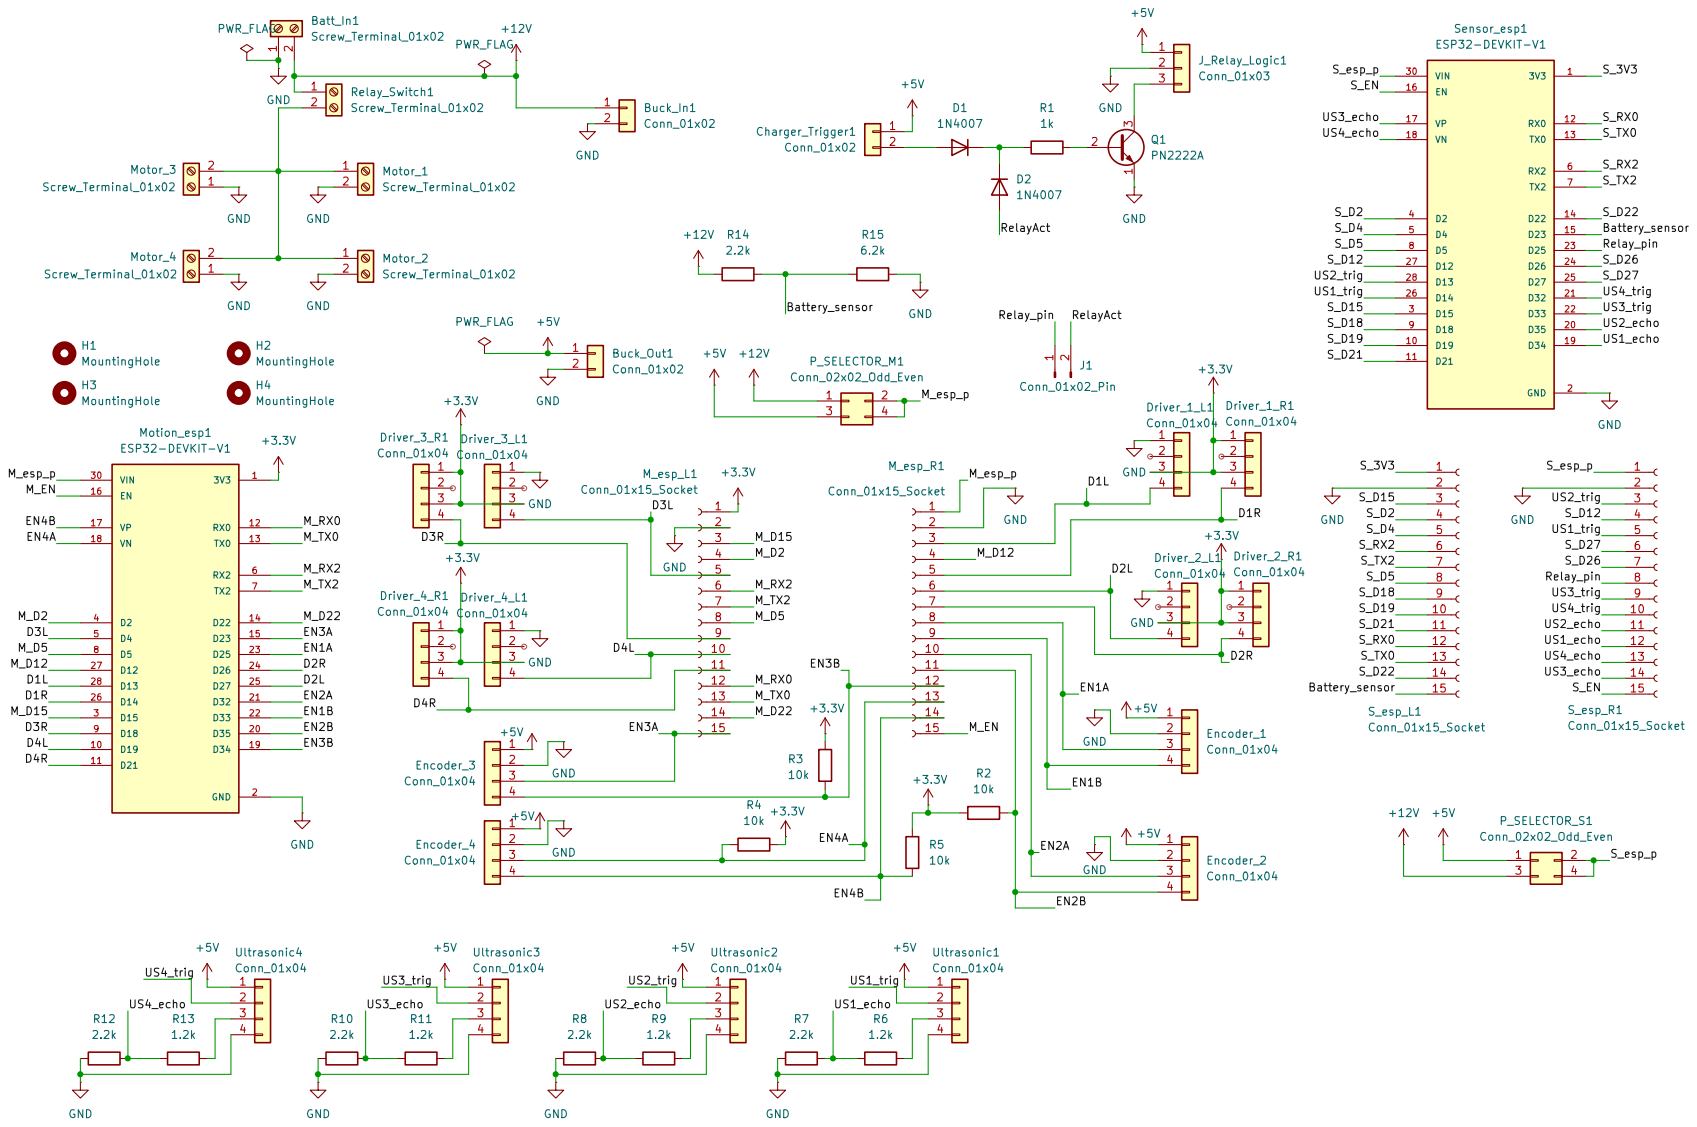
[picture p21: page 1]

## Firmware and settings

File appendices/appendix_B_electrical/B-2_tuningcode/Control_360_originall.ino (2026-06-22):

#include <WiFi.h>
#include <WebServer.h>
#include <math.h>
#include <freertos/FreeRTOS.h>
#include <freertos/task.h>
#include <freertos/semphr.h>

const char* ssid = "ESP32-Tuning-Rig";
const char* password = "12345678";

const float COUNTS_PER_REV = 360.0; 

// --- Pin Arrays ---
const int encA[4]   = {35, 36, 33, 34};
const int encB[4]   = {32, 39, 25, 23};
const int rPwm[4]   = {27, 21, 13, 18};
const int lPwm[4]   = {26, 19, 14, 4};

// --- Telemetry Data ---
volatile long pulseCount[4] = {0, 0, 0, 0};
long lastPulseCount[4] = {0, 0, 0, 0};
float rawRpm[4] = {0, 0, 0, 0};
float filteredRpm[4] = {0, 0, 0, 0}; 

// --- Control Variables ---
String currentDir = "stop";
bool maxPowerOverride = false;

// Independent Tuning Parameters
float baseRpm[4] = {50.0, 50.0, 50.0, 50.0}; 
float Kp[4] = {3.5,1.9, 1.7, 2.1};  
float Ki[4] = {1, 1, 1, 1};
float Kd[4] = {0, 0, 0, 0}; 
float alpha = 0.45; 

float targetRpm[4] = {0, 0, 0, 0};
float errorSum[4] = {0, 0, 0, 0}; 
float lastError[4] = {0, 0, 0, 0};      
int pwmOut[4] = {0, 0, 0, 0};     
int struggleCount[4] = {0, 0, 0, 0}; // Tracks how long a wheel fails to reach target

WebServer server(80);
SemaphoreHandle_t stateMutex;

// --- 4x ISRs ---
void IRAM_ATTR isr0() { static int lA=0, lB=0; int cA = digitalRead(encA[0]), cB = digitalRead(encB[0]); if(cA!=lA || cB!=lB) { if((lA==LOW&&cA==HIGH&&cB==LOW)||(lA==HIGH&&cA==LOW&&cB==HIGH)||(lB==LOW&&cB==HIGH&&cA==HIGH)||(lB==HIGH&&cB==LOW&&cA==LOW)) pulseCount[0]++; else pulseCount[0]--; } lA=cA; lB=cB; }
void IRAM_ATTR isr1() { static int lA=0, lB=0; int cA = digitalRead(encA[1]), cB = digitalRead(encB[1]); if(cA!=lA || cB!=lB) { if((lA==LOW&&cA==HIGH&&cB==LOW)||(lA==HIGH&&cA==LOW&&cB==HIGH)||(lB==LOW&&cB==HIGH&&cA==HIGH)||(lB==HIGH&&cB==LOW&&cA==LOW)) pulseCount[1]++; else pulseCount[1]--; } lA=cA; lB=cB; }
void IRAM_ATTR isr2() { static int lA=0, lB=0; int cA = digitalRead(encA[2]), cB = digitalRead(encB[2]); if(cA!=lA || cB!=lB) { if((lA==LOW&&cA==HIGH&&cB==LOW)||(lA==HIGH&&cA==LOW&&cB==HIGH)||(lB==LOW&&cB==HIGH&&cA==HIGH)||(lB==HIGH&&cB==LOW&&cA==LOW)) pulseCount[2]++; else pulseCount[2]--; } lA=cA; lB=cB; }
void IRAM_ATTR isr3() { static int lA=0, lB=0; int cA = digitalRead(encA[3]), cB = digitalRead(encB[3]); if(cA!=lA || cB!=lB) { if((lA==LOW&&cA==HIGH&&cB==LOW)||(lA==HIGH&&cA==LOW&&cB==HIGH)||(lB==LOW&&cB==HIGH&&cA==HIGH)||(lB==HIGH&&cB==LOW&&cA==LOW)) pulseCount[3]++; else pulseCount[3]--; } lA=cA; lB=cB; }

// --- Hardware  ---
void updateMotors() {
  for(int i = 0; i < 4; i++) {
    bool isLeftMotor = (i == 0 || i == 2);
    
    if (currentDir == "fwd" || maxPowerOverride) {
      analogWrite(rPwm[i], pwmOut[i]); analogWrite(lPwm[i], 0);
    } else if (currentDir == "rev") {
      analogWrite(rPwm[i], 0); analogWrite(lPwm[i], pwmOut[i]); 
    } else if (currentDir == "left") {
      if (isLeftMotor) { analogWrite(rPwm[i], 0); analogWrite(lPwm[i], pwmOut[i]); } 
      else             { analogWrite(rPwm[i], pwmOut[i]); analogWrite(lPwm[i], 0); }
    } else if (currentDir == "right") {
      if (isLeftMotor) { analogWrite(rPwm[i], pwmOut[i]); analogWrite(lPwm[i], 0); } 
      else             { analogWrite(rPwm[i], 0); analogWrite(lPwm[i], pwmOut[i]); }
    } else {
      analogWrite(rPwm[i], 0); analogWrite(lPwm[i], 0);
    }
  }
}

// --- HTML Dashboard ---
const char index_html[] PROGMEM = R"rawliteral(
<!DOCTYPE html><html><head>
<meta name='viewport' content='width=device-width, initial-scale=1'>
<style>
  body { font-family: sans-serif; background: #222; color: #fff; text-align: center; margin: 0; padding: 10px;}
  .grid { display: grid; grid-template-columns: 1fr 1fr; gap: 10px; max-width: 900px; margin: auto; }
  .card { background: #333; padding: 10px; border-radius: 8px; box-shadow: 0 2px 5px rgba(0,0,0,0.5); }
  .controls { margin-bottom: 20px; }
  .btn { background: #555; color: white; border: none; padding: 10px 15px; font-size: 14px; border-radius: 5px; cursor: pointer; margin: 2px; transition: background 0.3s;}
  .btn-stop { background: #dc3545; font-weight: bold;}
  .btn-danger { background: #ffc107; color: black; font-weight: bold; width: 100%; padding: 15px; margin-top: 10px;}
  input { width: 50px; padding: 5px; margin: 2px; text-align: center; background: #444; color: #fff; border: 1px solid #666; border-radius: 3px;}
  canvas { background: #111; width: 100%; height: 120px; border-radius: 4px; margin-top: 10px;}
  .metrics { font-size: 0.9em; color: #aaa; }
  .val-f { color: #00aaff; font-weight: bold;}
  .val-r { color: #888; }
</style>
</head><body>
  <h2>Robot Tuning Studio</h2>
  
  <div class="controls">
    <button class="btn" onclick="sendCmd('/dir?state=fwd')">FWD</button><br>
    <button class="btn" onclick="sendCmd('/dir?state=left')">LEFT</button>
    <button class="btn btn-stop" onclick="sendCmd('/dir?state=stop')">STOP</button>
    <button class="btn" onclick="sendCmd('/dir?state=right')">RIGHT</button><br>
    <button class="btn" onclick="sendCmd('/dir?state=rev')">REV</button><br>
    <button class="btn btn-danger" onmousedown="sendCmd('/maxPower?state=1')" onmouseup="sendCmd('/maxPower?state=0')" ontouchstart="sendCmd('/maxPower?state=1')" ontouchend="sendCmd('/maxPower?state=0')">HOLD FOR MAX PWM (Bypass PID)</button>
    
    <div style="margin-top:15px;">
      <label>Global Alpha (Filter): </label>
      <input type="number" step="0.05" id="g_alpha"> 
      <button class="btn" id="btn_alpha" onclick="updateAlpha()">Set Alpha</button>
    </div>
  </div>

  <div class="grid" id="motors"></div>

  <script>
    const labels = ["FL", "FR", "RL", "RR"];
    let history = [[], [], [], []];
    const MAX_PTS = 50;
    
    let initialLoad = true; 

    let html = "";
    for(let i=0; i<4; i++) {
      html += `<div class="card">
        <h3>${labels[i]} Motor</h3>
        Base Tgt: <input type="number" id="t${i}">
        Kp: <input type="number" step="0.1" id="p${i}">
        Ki: <input type="number" step="0.1" id="i${i}">
        Kd: <input type="number" step="0.01" id="d${i}">
        <button class="btn" id="btn_apply_${i}" onclick="updateM(${i})">Apply</button>
        <div class="metrics">Filt: <span class="val-f" id="f${i}">0</span> | Raw: <span class="val-r" id="r${i}">0</span> | PWM: <span id="pwm${i}">0</span></div>
        <canvas id="c${i}" width="400" height="120"></canvas>
      </div>`;
    }
    document.getElementById('motors').innerHTML = html;

    function sendCmd(url) { 
      let sep = url.includes('?') ? '&' : '?';
      fetch(url + sep + '_cb=' + Date.now()); 
    }

    function updateM(i) {
      let btn = document.getElementById('btn_apply_'+i);
      btn.innerText = "OK!";
      btn.style.background = "#28a745"; 
      
      let t = document.getElementById('t'+i).value;
      let p = document.getElementById('p'+i).value;
      let ki = document.getElementById('i'+i).value;
      let kd = document.getElementById('d'+i).value;
      
      fetch(`/tune?m=${i}&t=${t}&p=${p}&i=${ki}&d=${kd}&_cb=${Date.now()}`).then(() => {
        setTimeout(() => {
          btn.innerText = "Apply";
          btn.style.background = "#555";
        }, 1000);
      });
    }

    function updateAlpha() {
      let btn = document.getElementById('btn_alpha');
      btn.innerText = "OK!";
      btn.style.background = "#28a745"; 
      
      let val = document.getElementById('g_alpha').value;
      
      fetch(`/alpha?val=${val}&_cb=${Date.now()}`).then(() => {
        setTimeout(() => {
          btn.innerText = "Set Alpha";
          btn.style.background = "#555";
        }, 1000);
      });
    }

    function drawChart(i, target, filt, raw) {
      let cvs = document.getElementById('c'+i);
      let ctx = cvs.getContext('2d');
      history[i].push({t: target, f: filt, r: raw});
      if(history[i].length > MAX_PTS) history[i].shift();

      ctx.clearRect(0, 0, cvs.width, cvs.height);
      let maxH = 150; 
      let dx = cvs.width / MAX_PTS;

      function plot(key, color, width) {
        ctx.beginPath();
        ctx.strokeStyle = color;
        ctx.lineWidth = width;
        for(let j=0; j<history[i].length; j++) {
          let x = j * dx;
          let y = cvs.height - ((history[i][j][key] / maxH) * cvs.height);
          if(j===0) ctx.moveTo(x,y); else ctx.lineTo(x,y);
        }
        ctx.stroke();
      }
      plot('r', 'rgba(255,255,255,0.2)', 1); 
      plot('t', '#ff4444', 1);               
      plot('f', '#00aaff', 2);               
    }

    function pollData() {
      fetch('/data?_cb=' + Date.now())
        .then(r => r.json())
        .then(d => {
          if(initialLoad) {
            document.getElementById('g_alpha').value = d.alpha;
          }

          for(let i=0; i<4; i++) {
            let m = d.m[i];
            
            document.getElementById('f'+i).innerText = m.f.toFixed(1);
            document.getElementById('r'+i).innerText = m.r.toFixed(1);
            document.getElementById('pwm'+i).innerText = m.pwm;
            drawChart(i, m.tgt, m.f, m.r); 
            
            if(initialLoad) {
              document.getElementById('t'+i).value = m.base; 
              document.getElementById('p'+i).value = m.p;
              document.getElementById('i'+i).value = m.i;
              document.getElementById('d'+i).value = m.d;
            }
          }
          
          initialLoad = false; 
          setTimeout(pollData, 150); 
        })
        .catch(e => {
          setTimeout(pollData, 500); 
        });
    }

    pollData();
  </script>
</body></html>
)rawliteral";

// --- FreeRTOS Tasks ---

void controlLoopTask(void *pvParameters) {
  TickType_t xLastWakeTime = xTaskGetTickCount();
  const TickType_t xFrequency = pdMS_TO_TICKS(100); 
  const float timeInMinutes = 100.0 / 60000.0;      

  while(true) {
    vTaskDelayUntil(&xLastWakeTime, xFrequency);

    noInterrupts();
    long currentPulses[4];
    for(int i=0; i<4; i++) currentPulses[i] = pulseCount[i];
    interrupts();

    if (xSemaphoreTake(stateMutex, portMAX_DELAY)) {
      
      // 1. Calculate Actual RPM
      for(int i = 0; i < 4; i++) {
        long deltaPulses = currentPulses[i] - lastPulseCount[i];
        rawRpm[i] = abs(((float)deltaPulses / COUNTS_PER_REV) / timeInMinutes); 
        filteredRpm[i] = (alpha * rawRpm[i]) + ((1.0 - alpha) * filteredRpm[i]);
        lastPulseCount[i] = currentPulses[i];
      }

      // 2. Control Logic
      if (maxPowerOverride) {
        for(int i=0; i<4; i++) {
          pwmOut[i] = 255;
          errorSum[i] = 0; 
          lastError[i] = 0;
          targetRpm[i] = baseRpm[i]; 
        }
      } else {
        
        // --- THE PROPORTIONAL GOVERNOR (WITH TIMEOUT) ---
        float targetRatio = 1.0; 
        
        for(int i = 0; i < 4; i++) {
          // If a wheel is maxed out and missing its target by more than 5%
          if (baseRpm[i] > 5.0 && pwmOut[i] >= 250 && filteredRpm[i] < (baseRpm[i] * 0.95)) {
            struggleCount[i]++;
            if (struggleCount[i] > 20) struggleCount[i] = 20; // Cap it
          } else {
            if (struggleCount[i] > 0) struggleCount[i]--; 
          }

          // ONLY apply the penalty if it has been struggling for 5 loops (500 milliseconds)
          if (struggleCount[i] >= 5) {
            float ratio = filteredRpm[i] / baseRpm[i];
            if (ratio < targetRatio) targetRatio = ratio; 
          }
        }

        // Apply a low-pass filter to the ratio itself so the target lines glide smoothly
        static float smoothedRatio = 1.0;
        if (currentDir == "stop") smoothedRatio = 1.0; // Reset completely on stop
        else smoothedRatio = (0.2 * targetRatio) + (0.8 * smoothedRatio);

        // --- PID CALCULATION ---
        for(int i = 0; i < 4; i++) {
          if (currentDir == "stop" || baseRpm[i] == 0) {
            pwmOut[i] = 0; errorSum[i] = 0; lastError[i] = 0; struggleCount[i] = 0;
            targetRpm[i] = 0; 
          } else {
            
            // Multiply the target by our smooth, delayed governor ratio
            targetRpm[i] = baseRpm[i] * smoothedRatio; 
            
            float error = targetRpm[i] - filteredRpm[i];
            errorSum[i] += error;
            
            float iLimit = (Ki[i] > 0) ? (255.0 / Ki[i]) : 0;
            if (errorSum[i] > iLimit) errorSum[i] = iLimit;
            if (errorSum[i] < -iLimit) errorSum[i] = -iLimit;

            float dError = error - lastError[i];
            lastError[i] = error;
            
            float output = (Kp[i] * error) + (Ki[i] * errorSum[i]) + (Kd[i] * dError);
            
            if (output > 255) output = 255;
            if (output < 0) output = 0;
            pwmOut[i] = (int)output;
          }
        }
      }
      
      updateMotors();
      xSemaphoreGive(stateMutex);
    }
  }
}

void serverTask(void *pvParameters) {
  while(true) {
    server.handleClient();
    vTaskDelay(pdMS_TO_TICKS(10)); 
  }
}

void setup() {
  Serial.begin(115200);
  stateMutex = xSemaphoreCreateMutex();

  for(int i = 0; i < 4; i++) {
    pinMode(encA[i], INPUT_PULLUP); pinMode(encB[i], INPUT_PULLUP);
    pinMode(rPwm[i], OUTPUT); pinMode(lPwm[i], OUTPUT);
  }
  updateMotors();

  attachInterrupt(digitalPinToInterrupt(encA[0]), isr0, CHANGE); attachInterrupt(digitalPinToInterrupt(encB[0]), isr0, CHANGE);
  attachInterrupt(digitalPinToInterrupt(encA[1]), isr1, CHANGE); attachInterrupt(digitalPinToInterrupt(encB[1]), isr1, CHANGE);
  attachInterrupt(digitalPinToInterrupt(encA[2]), isr2, CHANGE); attachInterrupt(digitalPinToInterrupt(encB[2]), isr2, CHANGE);
  attachInterrupt(digitalPinToInterrupt(encA[3]), isr3, CHANGE); attachInterrupt(digitalPinToInterrupt(encB[3]), isr3, CHANGE);

  WiFi.softAP(ssid, password);

  server.on("/", []() { server.send_P(200, "text/html", index_html); });

  server.on("/data", []() {
    String json = "";
    if (xSemaphoreTake(stateMutex, portMAX_DELAY)) {
      json = "{\"alpha\":" + String(alpha) + ",\"m\":[";
      for(int i = 0; i < 4; i++) {
        json += "{\"f\":" + String(filteredRpm[i]) + ",\"r\":" + String(rawRpm[i]);
        json += ",\"tgt\":" + String(targetRpm[i]) + ",\"base\":" + String(baseRpm[i]) + ",\"pwm\":" + String(pwmOut[i]);
        json += ",\"p\":" + String(Kp[i]) + ",\"i\":" + String(Ki[i]) + ",\"d\":" + String(Kd[i]) + "}";
        if(i < 3) json += ",";
      }
      json += "]}";
      xSemaphoreGive(stateMutex);
    }
    server.send(200, "application/json", json);
  });

  server.on("/dir", []() {
    if (server.hasArg("state") && xSemaphoreTake(stateMutex, portMAX_DELAY)) {
      currentDir = server.arg("state"); 
      xSemaphoreGive(stateMutex);
    }
    server.send(200, "text/plain", "OK");
  });

  server.on("/maxPower", []() {
    if (server.hasArg("state") && xSemaphoreTake(stateMutex, portMAX_DELAY)) {
      maxPowerOverride = (server.arg("state") == "1");
      xSemaphoreGive(stateMutex);
    }
    server.send(200, "text/plain", "OK");
  });

  server.on("/tune", []() {
    if (server.hasArg("m") && xSemaphoreTake(stateMutex, portMAX_DELAY)) {
      int m = server.arg("m").toInt();
      if(m >= 0 && m < 4) {
        if(server.hasArg("t")) baseRpm[m] = server.arg("t").toFloat();
        if(server.hasArg("p")) Kp[m] = server.arg("p").toFloat();
        if(server.hasArg("i")) Ki[m] = server.arg("i").toFloat();
        if(server.hasArg("d")) Kd[m] = server.arg("d").toFloat();
      }
      xSemaphoreGive(stateMutex);
    }
    server.send(200, "text/plain", "OK");
  });

  server.on("/alpha", []() {
    if (server.hasArg("val") && xSemaphoreTake(stateMutex, portMAX_DELAY)) {
      alpha = server.arg("val").toFloat();
      xSemaphoreGive(stateMutex);
    }
    server.send(200, "text/plain", "OK");
  });

  server.begin();

  xTaskCreatePinnedToCore(controlLoopTask, "CtrlTask", 4096, NULL, 2, NULL, 1);
  xTaskCreatePinnedToCore(serverTask, "WebTask", 4096, NULL, 1, NULL, 0);
}

void loop() { vTaskDelete(NULL); }

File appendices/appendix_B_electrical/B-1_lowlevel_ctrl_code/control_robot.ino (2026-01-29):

#include <WiFi.h>
#include <WebServer.h>
#include <ArduinoOTA.h>

// ================================================================
// 1. PIN DEFINITIONS (Assign your pins here)
// ================================================================

// Motor 1 (Front Left)
#define M1_RPWM  26  // Forward Pin
#define M1_LPWM  27  // Backward Pin
#define M1_EN_A  35  // Encoder A
#define M1_EN_B  32  // Encoder B

// Motor 2 (Front Right)
#define M2_RPWM  21
#define M2_LPWM  19
#define M2_EN_A  36
#define M2_EN_B  39

// Motor 3 (Rear Left)
#define M3_RPWM  14
#define M3_LPWM  13
#define M3_EN_A  33
#define M3_EN_B  25

// Motor 4 (Rear Right)
#define M4_RPWM  18
#define M4_LPWM  4
#define M4_EN_A  34
#define M4_EN_B  23

// ================================================================
// 2. CONFIGURATION CONSTANTS
// ================================================================

// WiFi Credentials
const char* ssid = "MyESP32_AP";
const char* password = "12345678";

// Encoder Resolution
const float PPR = 100.0; // Pulses Per Revolution (Change this to your encoder's value)
const unsigned long RPM_INTERVAL = 100; // Calculate RPM every 100ms

// ================================================================
// 3. GLOBAL VARIABLES
// ================================================================

WebServer server(80);

// Encoder Ticks (Volatile because they are changed in ISR)
volatile long m1_ticks = 0;
volatile long m2_ticks = 0;
volatile long m3_ticks = 0;
volatile long m4_ticks = 0;

// RPM Values
float m1_rpm = 0;
float m2_rpm = 0;
float m3_rpm = 0;
float m4_rpm = 0;

// Timer for RPM calculation
unsigned long previousMillis = 0;

// CONTROL VARIABLES
int motorSpeed = 150; // Default speed (0-255)
int moveState = 0;    // 0=Stop, 1=Fwd, 2=Bwd, 3=Left, 4=Right

// ================================================================
// 4. INTERRUPT SERVICE ROUTINES (ISRs)
// ================================================================

// Handle Motor 1 Encoder
void IRAM_ATTR isr_m1() {
  if (digitalRead(M1_EN_B) == digitalRead(M1_EN_A)) {
    m1_ticks++;
  } else {
    m1_ticks--;
  }
}

// Handle Motor 2 Encoder
void IRAM_ATTR isr_m2() {
  if (digitalRead(M2_EN_B) == digitalRead(M2_EN_A)) {
    m2_ticks++;
  } else {
    m2_ticks--;
  }
}

// Handle Motor 3 Encoder
void IRAM_ATTR isr_m3() {
  if (digitalRead(M3_EN_B) == digitalRead(M3_EN_A)) {
    m3_ticks++;
  } else {
    m3_ticks--;
  }
}

// Handle Motor 4 Encoder
void IRAM_ATTR isr_m4() {
  if (digitalRead(M4_EN_B) == digitalRead(M4_EN_A)) {
    m4_ticks++;
  } else {
    m4_ticks--;
  }
}

// ================================================================
// 5. MOTOR CONTROL
// ================================================================

void setMotor(int rpwm, int lpwm, int speed) {
  if (speed > 0) {
    analogWrite(rpwm, speed);
    analogWrite(lpwm, 0);
  } else if (speed < 0) {
    analogWrite(rpwm, 0);
    analogWrite(lpwm, -speed);
  } else {
    analogWrite(rpwm, 0);
    analogWrite(lpwm, 0);
  }
}

// Function to apply the current speed based on the current state
void updateMotors() {
  int spd = motorSpeed; // Use the global slider value

  switch (moveState) {
    case 0: // STOP
      setMotor(M1_RPWM, M1_LPWM, 0); setMotor(M2_RPWM, M2_LPWM, 0);
      setMotor(M3_RPWM, M3_LPWM, 0); setMotor(M4_RPWM, M4_LPWM, 0);
      break;
    case 1: // FORWARD
      setMotor(M1_RPWM, M1_LPWM, -spd); setMotor(M2_RPWM, M2_LPWM, spd);
      setMotor(M3_RPWM, M3_LPWM, -spd); setMotor(M4_RPWM, M4_LPWM, spd);
      break;
    case 2: // BACKWARD
      setMotor(M1_RPWM, M1_LPWM, spd); setMotor(M2_RPWM, M2_LPWM, -spd);
      setMotor(M3_RPWM, M3_LPWM, spd); setMotor(M4_RPWM, M4_LPWM, -spd);
      break;
    case 3: // LEFT (Turn on spot)
      setMotor(M1_RPWM, M1_LPWM, spd); setMotor(M2_RPWM, M2_LPWM, spd);
      setMotor(M3_RPWM, M3_LPWM, spd); setMotor(M4_RPWM, M4_LPWM, spd);
      break;
    case 4: // RIGHT (Turn on spot)
      setMotor(M1_RPWM, M1_LPWM, -spd); setMotor(M2_RPWM, M2_LPWM, -spd);
      setMotor(M3_RPWM, M3_LPWM, -spd); setMotor(M4_RPWM, M4_LPWM, -spd);
      break;
  }
}

// ================================================================
// 6. WEB SERVER
// ================================================================

void handleRoot() {
  String html = "<html><head><title>Robot Control</title>";
  html += "<meta name='viewport' content='width=device-width, initial-scale=1'>";
  html += "<style>";
  html += "body { font-family: sans-serif; text-align: center; margin-top: 50px; }";
  html += "button { width: 80px; height: 80px; font-size: 20px; margin: 5px; border-radius: 10px; }";
  html += ".slider { width: 300px; margin: 20px; }";
  html += "</style></head><body>";
  
  html += "<h1>ESP32 Robot</h1>";
  html += "<p><b>Speed: <span id='speedVal'>" + String(motorSpeed) + "</span></b></p>";
  
  // SLIDER
  html += "<input type='range' min='0' max='255' value='" + String(motorSpeed) + "' class='slider' id='spdSlider' oninput='updateSpeed(this.value)'>";
  
  html += "<br><br>";
  
  // BUTTONS
  html += "<button onclick=\"fetch('/fwd')\">&#8593;</button><br>";
  html += "<button onclick=\"fetch('/left')\">&#8592;</button>";
  html += "<button onclick=\"fetch('/stop')\" style='background-color:#ffcccc'>STOP</button>";
  html += "<button onclick=\"fetch('/right')\">&#8594;</button><br>";
  html += "<button onclick=\"fetch('/bwd')\">&#8595;</button>";

  html += "<p>RPM FL: <span id='rpm1'>0</span> | FR: <span id='rpm2'>0</span></p>";
  
  // JAVASCRIPT
  html += "<script>";
  html += "function updateSpeed(val) {";
  html += "  document.getElementById('speedVal').innerText = val;";
  html += "  fetch('/setSpeed?val=' + val);";
  html += "}";
  html += "setInterval(function(){";
  html += "  fetch('/rpm').then(r => r.text()).then(d => {";
  html += "    let parts = d.split(',');";
  html += "    if(parts.length >= 2) {";
  html += "      document.getElementById('rpm1').innerText = parts[0];";
  html += "      document.getElementById('rpm2').innerText = parts[1];";
  html += "    }";
  html += "  });";
  html += "}, 500);";
  html += "</script>";
  
  html += "</body></html>";
  server.send(200, "text/html", html);
}

// Handlers for Buttons
void handleForward() { moveState = 1; updateMotors(); server.send(200, "text/plain", "OK"); }
void handleBackward() { moveState = 2; updateMotors(); server.send(200, "text/plain", "OK"); }
void handleLeft() { moveState = 3; updateMotors(); server.send(200, "text/plain", "OK"); }
void handleRight() { moveState = 4; updateMotors(); server.send(200, "text/plain", "OK"); }
void handleStop() { moveState = 0; updateMotors(); server.send(200, "text/plain", "OK"); }

// Handler for Slider
void handleSetSpeed() {
  if (server.hasArg("val")) {
    motorSpeed = server.arg("val").toInt();
    updateMotors(); // Apply new speed immediately if robot is moving
  }
  server.send(200, "text/plain", "OK");
}
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

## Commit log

2026-01-29 commit commit
    [Acrylic plate ___.SLDPRT, Arms link.SLDPRT, Battery Sizing GP.xlsx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]
2026-01-29 commiting commit
    [BOM.xlsx]
2026-06-22 Refactor folder structure, add new content, and remove old files
    [Acrylic plate ___.SLDPRT, Arms link.SLDPRT, BOM.xlsx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]
